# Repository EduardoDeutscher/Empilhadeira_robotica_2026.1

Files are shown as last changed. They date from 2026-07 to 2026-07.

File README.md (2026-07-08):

# Projeto Empilhadeira Robótica 2026.1

Projeto desenvolvido para a disciplina ENG4061 – Projeto de Robótica  
Prof. João Ricardo | Turma 3VA

**Integrantes:**
- Eduardo Deutscher — 2210218
- Eric Siemsen — 2210608
- Marcelo Bessa — 2220426
- Marius

---

## Descrição do Projeto

Empilhadeira robótica autônoma capaz de localizar paletes por meio de visão computacional utilizando AprilTags. O sistema realiza uma busca ativa por uma tag específica e, ao identificá-la, utiliza o algoritmo Pure Pursuit para se locomover autonomamente até o objetivo. Além do modo autônomo, o robô suporta operação manual completa, permitindo o controle em tempo real da movimentação e do garfo motorizado para elevação da carga. A transição entre os modos e o controle manual são realizados via dashboard web, acessível por qualquer dispositivo conectado à mesma rede Wi-Fi, sem necessidade de instalar nenhum aplicativo.

---

## Arquitetura do Sistema

    Câmera ⭢ Raspberry Pi ⭢ Arduino ⭢ Motores
                   ⭡
               Dashboard

O Raspberry Pi é responsável por toda a lógica de alto nível: visão computacional, máquina de estados (Busca → Pure Pursuit → Manual) e servidor web Flask com WebSockets. O Arduino Mega executa apenas os comandos recebidos via serial, acionando os motores com PWM em tempo real. A comunicação entre os dois é feita por cabo USB (Serial UART 115200 bps).

---

## Hardware Necessário

| Componente | Quantidade |
|---|---|
| Raspberry Pi 3 | 1 |
| Arduino Mega 2560 | 1 |
| Motor DC LEGO NXT 53787 (encoder) | 2 |
| Motor de passo NEMA 17 | 1 |
| Driver A4988 | 1 |
| Ponte H L298N | 1 |
| Bateria Li-Ion 18650 3.7V | 3 |
| BMS 3S 40A | 1 |
| Regulador DC-DC Buck LM2596 | 1 |
| Câmera Multilaser 480p 30fps | 1 |
| Barras de aço cilíndricas (guias) | 2 |
| Rolamentos lineares LM6UU/LM8UU | 4 |
| Filamento PLA (~1kg) | 1 |

---

---

## Dependências e Instalação

### Raspberry Pi

Crie um ambiente virtual para evitar conflitos com o sistema:

```bash
python3 -m venv ~/venv
source ~/venv/bin/activate
pip install flask flask-sock opencv-python-headless pupil-apriltags pyserial numpy
```

> Para rodar em sessões futuras, sempre ative o ambiente antes:
> ```bash
> source ~/venv/bin/activate
> ```

### Arduino IDE

Instalar via **Library Manager**:
- `AccelStepper` 

---

## Como Rodar

### 1. Subir o sketch no Arduino

- Abra `Robotica_arduino.c` na Arduino IDE
- Selecione a placa: **Ferramentas → Placa → Arduino Mega 2560**
- Selecione a porta correta em **Ferramentas → Porta**
- Clique em **Upload**

### 2. Conectar o Arduino ao Raspberry Pi via USB

O código tenta automaticamente `/dev/ttyACM0` e `/dev/ttyACM1`. Para verificar qual porta está sendo usada:

```bash
ls /dev/tty*
# antes e depois de conectar o cabo — a porta nova é a do Arduino
```

### 3. Rodar o servidor no Raspberry Pi

```bash
source ~/venv/bin/activate
python Robotica_raspberryPi.py
```

O terminal mostrará o IP e a porta ao iniciar. Aguarde as mensagens:
```bash
✅ Arduino conectado em /dev/ttyACM0!
✅ Câmera 0 conectada!
```

---

### 4. Acessar o dashboard

No celular ou notebook conectado na **mesma rede Wi-Fi** que o Pi, abra o navegador e acesse: `http://[Endereço IP]:5000` 

---

## Inicialização Automática (opcional)

Para o servidor subir automaticamente ao ligar o Pi, sem precisar de teclado ou SSH:

```bash
sudo nano /etc/rc.local
```

Adicione antes do `exit 0`:

```bash
sleep 15
source /home/pi/venv/bin/activate && cd /home/pi && python Robotica_raspberryPi.py &
```

Salve, reinicie o Pi e aguarde ~15 segundos após ligar para acessar o dashboard.

---

## Modos de Operação

### 🔍 Busca
Modo inicial autônomo. O robô para, faz um giro completo de 360° em pulsos (pausa entre cada pulso para a câmera ler sem desfoque), procurando a AprilTag alvo. Se não encontrar após a volta completa, avança um pouco para frente e repete. Se o timeout de busca for atingido (padrão: 300s), entra em modo **Parado**.

### 🎯 Pure Pursuit
Ativado ao detectar a AprilTag alvo. Opera em dois regimes:
- **Longe da tag:** Pure Pursuit clássico — calcula curvatura e decompõe em velocidades das rodas via cinemática diferencial, com rampa de desaceleração proporcional à distância.
- **Perto da tag** (< `DISTANCIA_PARAR`): para a translação e corrige apenas o ângulo girando no próprio eixo, com velocidade proporcional ao erro angular.

Ao atingir distância < 0,30 m, muda automaticamente para **Manual**.

### 🕹️ Manual
Controle total pelo dashboard. WASD para movimentação, J/K para o garfo. O slider de velocidade define a intensidade. Para retornar ao modo Busca, pressionar **Alternar Modo** no dashboard.

### ⏸️ Parado
Estado de segurança atingido por timeout de busca. Pressionar **Retomar Busca** no dashboard para reiniciar.

---

## Protocolo Serial (Pi → Arduino)

| Comando | Ação |
|---|---|
| `DE:1,VE:150,DD:1,VD:150\n`  | Move rodas com direção e velocidade PWM |
| `PARAR\n` | Para todos os motores |
| `SUBIR\n` | Garfo sobe (N passos definido no Arduino) |
| `DESCER\n` | Garfo desce (N passos definido no Arduino)  |
| `PARAR_GARFO\n` | Para o motor de passo |

Formato do comando de rodas: `DE` = direção esquerda (1/-1/0), `VE` = velocidade esquerda (0–200), `DD` = direção direita, `VD` = velocidade direita. Todos os valores são calculados pelo Pi; o Arduino apenas executa.

---

## Parâmetros Ajustáveis

Todos no topo de `Robotica_raspberryPi.py`:

| Variável | Padrão | Descrição |
|---|---|---|
| `TAG_ALVO` | `0` | ID da AprilTag a ser buscada (também ajustável no dashboard em tempo real) |
| `DISTANCIA_PARAR` | `0.30` | Distância em metros para considerar "chegou" |
| `ANGULO_ALINHADO` | `3.0`  | Graus de tolerância para considerar "alinhado" |
| `VEL_MAX` | `200`  | PWM máximo enviado aos motores (0–255) |
| `VEL_MIN` | `90` | PWM mínimo para vencer atrito estático |
| `NUM_PULSOS_360` | `12` | Número de pulsos para completar 360° na busca |
| `T_PULSO` | `0.5`  | Duração de cada pulso de giro (segundos) |
| `T_PAUSA_LEITURA` | `1.20` | Pausa entre pulsos para leitura da câmera (segundos) |
| `TIMEOUT_BUSCA_SEG`  | `300`  | Tempo máximo em busca antes de parar |
| `K_ANGULAR` | `2.5`  | Ganho da velocidade angular no Pure Pursuit |
| `L_CHASSI` | `0.15` | Distância entre rodas em metros (bitola) |

---

## Ligação dos Componentes

### Motores LEGO (tração) → Ponte H L298N → Arduino Mega

| Arduino Mega | Ponte H |
|---|---|
| Pino 11 | IN1 |
| Pino 10 | IN2 |
| Pino 13 | ENB |
| Pino 9 | IN3 |
| Pino 8 | IN4 |
| Pino 12 | ENA |
| GND | GND |

Alimentação da ponte: pack de baterias 12V → terminal VMOT.

### Motor NEMA 17 (garfo) → Driver A4988 → Arduino Mega

| Arduino Mega | A4988 |
|---|---|
| Pino 4 | STEP |
| Pino 5 | DIR |
| Pino 3 | ENABLE  |
| Pino 6 | VCC |
| GND | GND lógico |
| 5V | VDD |

Capacitor 100µF instalado em paralelo com VMOT e GND, o mais próximo possível do driver.  
Alimentação do driver: pack de baterias 12V → VMOT.

### Raspberry Pi → Arduino Mega

Conexão via cabo USB (Serial UART 115200 bps).  
Alimentação do Pi: regulador LM2596 (bateria 12V → 5V).

---

## Solução de Problemas Comuns

**Arduino não conecta:**
```bash
ls /dev/tty*  # verificar porta disponível
```
O código tenta `/dev/ttyACM0` e `/dev/ttyACM1` automaticamente. Tem reconexão automática em background se o cabo for desconectado.

**Câmera não abre:**
```bash
ls /dev/video*  # verificar índice disponível
```
O código tenta os índices 0, 1 e 2 automaticamente.

**Erro `externally-managed-environment` no pip:**
```bash
python3 -m venv ~/venv
source ~/venv/bin/activate
pip install flask flask-sock opencv-python-headless pupil-apriltags pyserial numpy
```

**Dashboard não abre pelo nome:**
Use o IP direto. Descobrir com `hostname -I` no Pi.

**Motores não reagem:**
Verificar baud rate no Serial Monitor (deve ser 115200) e confirmar que GND da fonte está conectado ao GND do Arduino.

---

## Modelagem

Link para o Onshape: `https://cad.onshape.com/documents/99c5d240e4870d25705ec42d/w/1db559e20b317aebbfff364a/e/47e8b66c013c91d15a91f58e`

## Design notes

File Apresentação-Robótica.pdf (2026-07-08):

# ENG4061 - Projeto de Robótica

Eduardo Deutscher - 2210218 Eric Siemsen - 2210608
Marcelo Bessa - 2220426
Marius -

# Objetivo

Navegação autônoma via AprilTags

Elevação de carga com garfo motorizado e controle manual

Controle manual via dashboard

# Nosso Robô

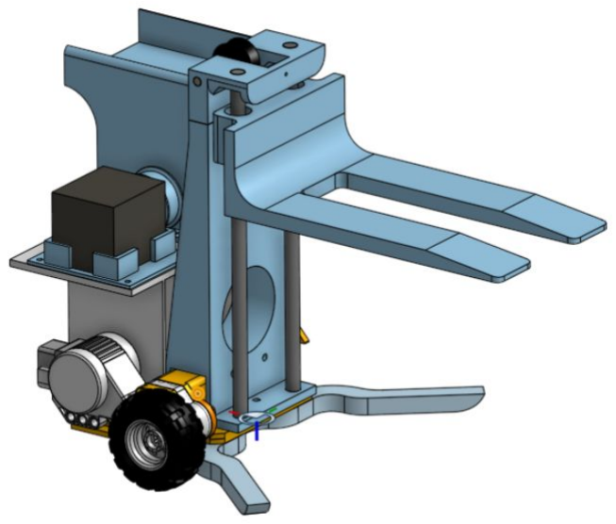
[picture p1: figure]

# Hardware

# Microcontroladores

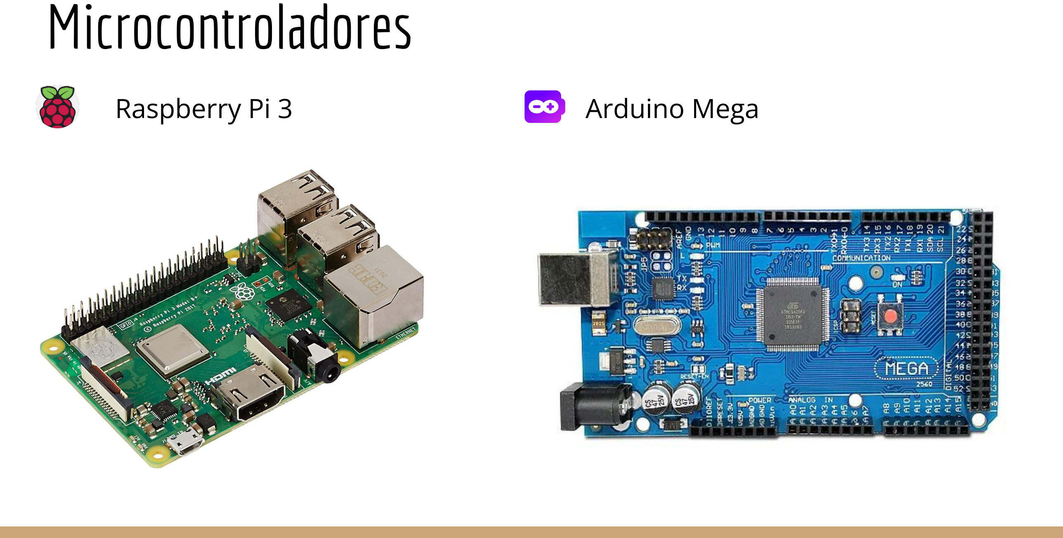
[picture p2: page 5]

Raspberry Pi 3 | Arduino Mega

# Motores

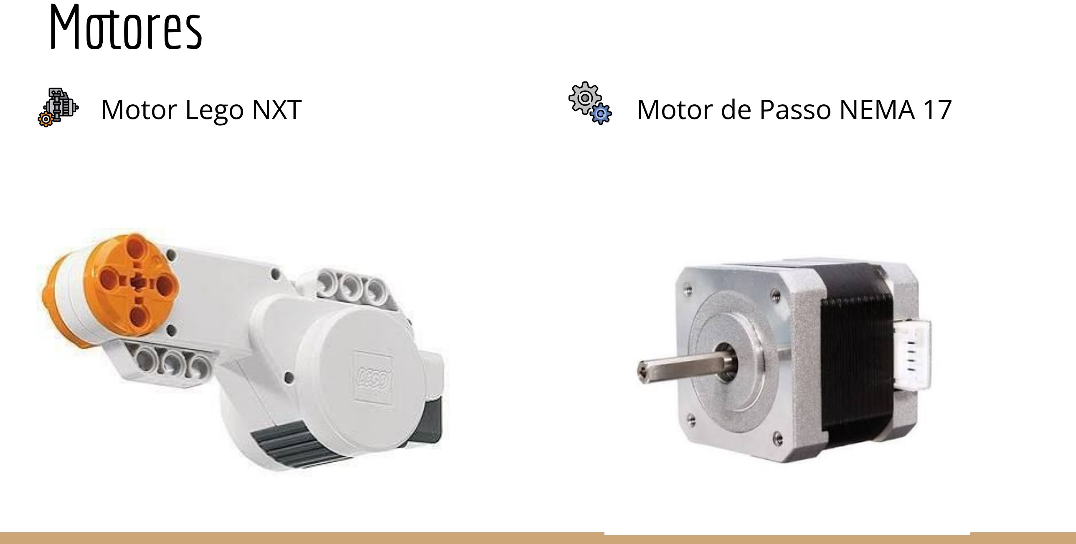
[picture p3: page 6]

Motor Lego NXT | Motor de Passo NEMA 17

# Driver e Ponte H

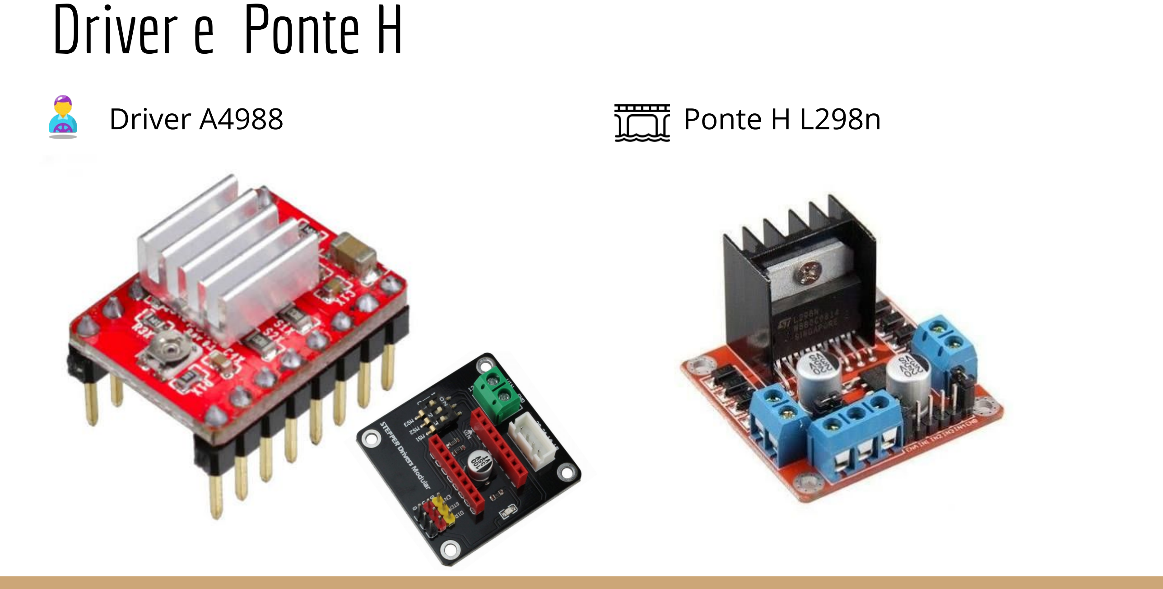
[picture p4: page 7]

Driver A4988 | Ponte H L298n

# Regulador de Tensão e Interruptores

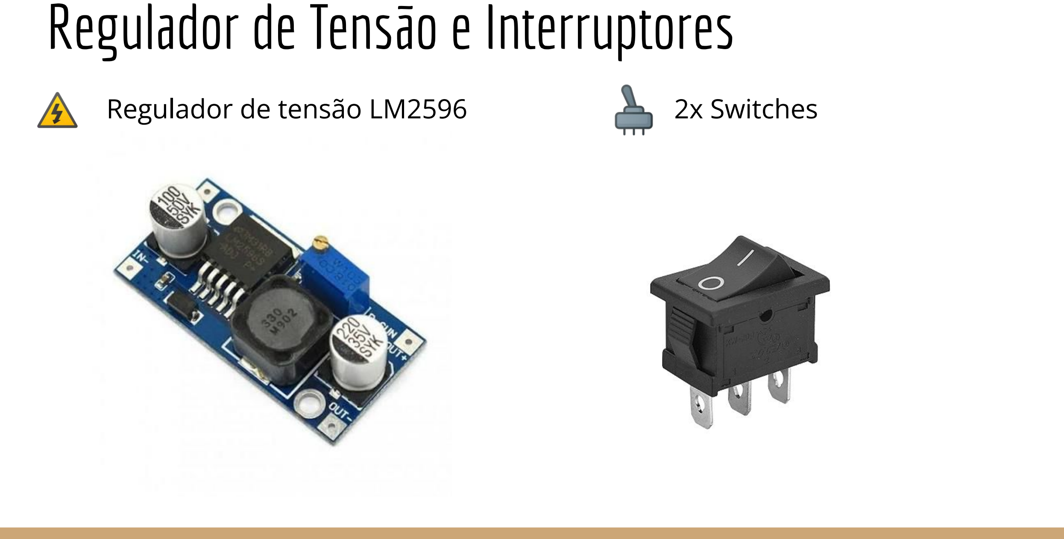
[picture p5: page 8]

Regulador de tensão LM2596 | 2x Switches

# Baterias

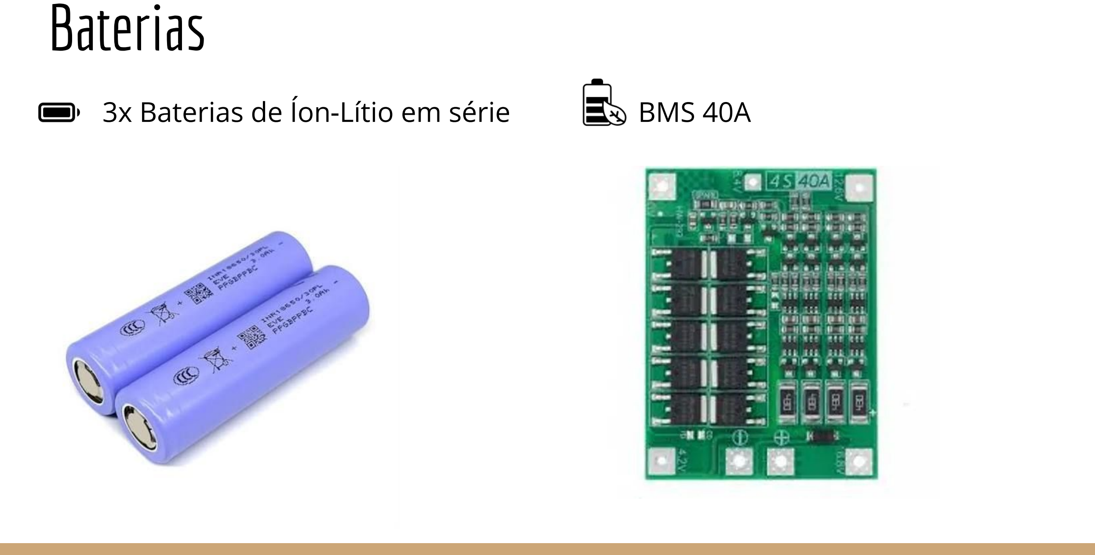
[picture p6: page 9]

3x Baterias de Íon-Lítio em série | BMS 40A

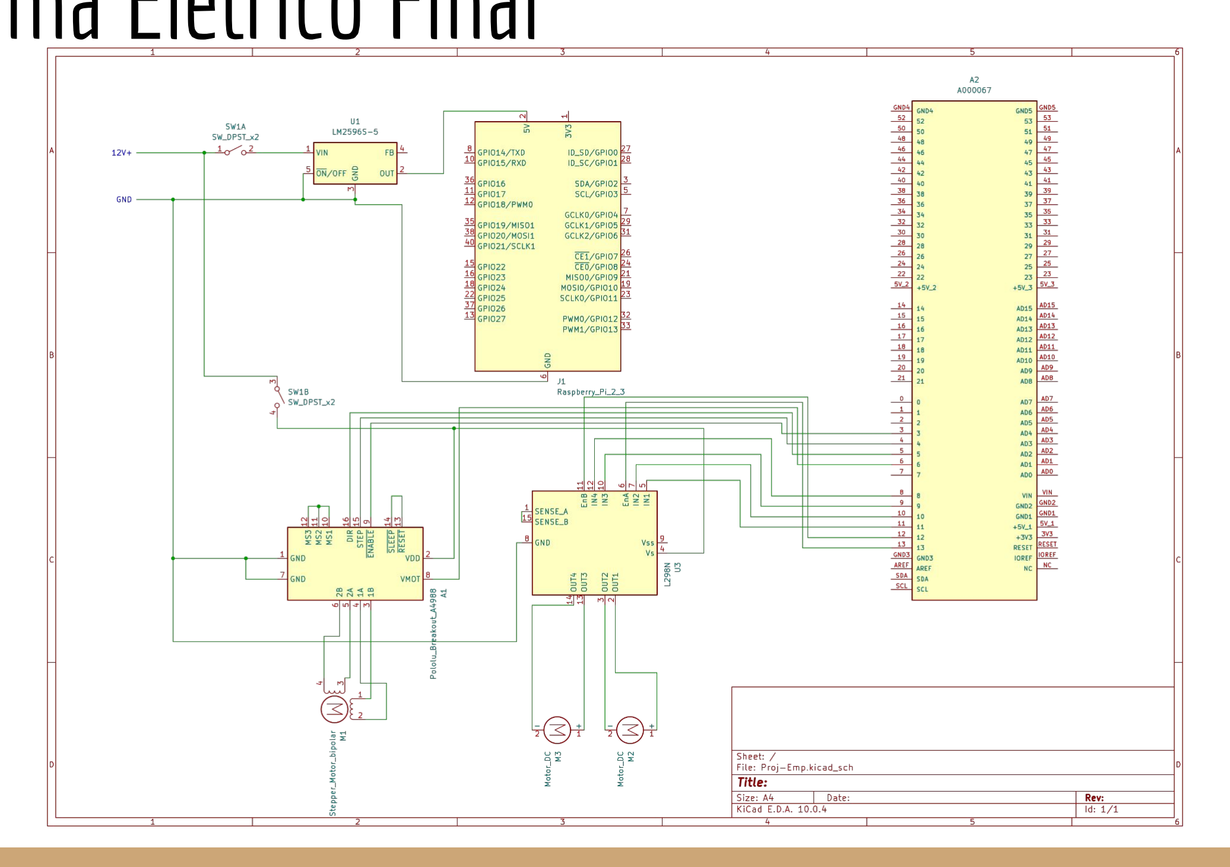
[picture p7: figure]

# Diagrama Elétrico Final

# Modelagem

# Modelagem

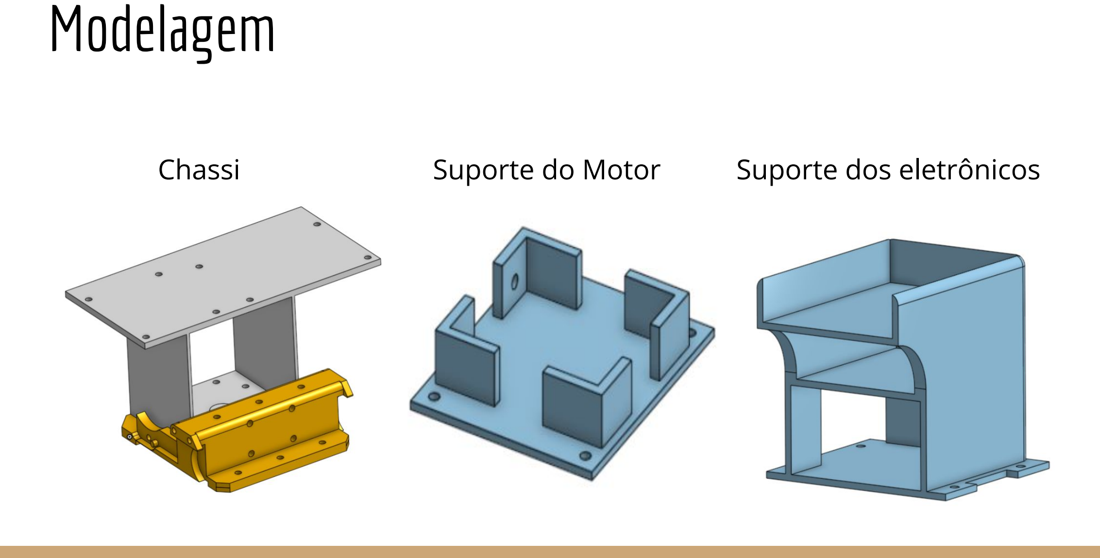
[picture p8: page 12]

Chassi | Suporte do Motor | Suporte dos eletrônicos
eletrônicoselMicros+Bateria

# Modelagem

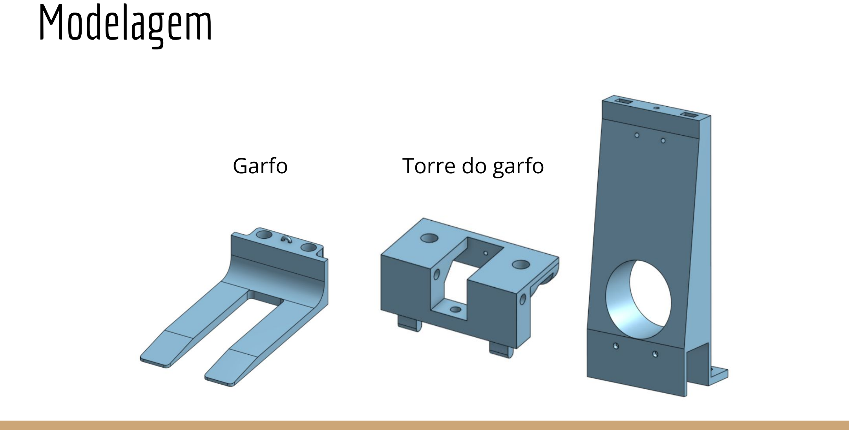
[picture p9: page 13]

Garfo | Torre do garfo

# Modelagem

Polia | Apoio Traseiro | Apoio Frontal

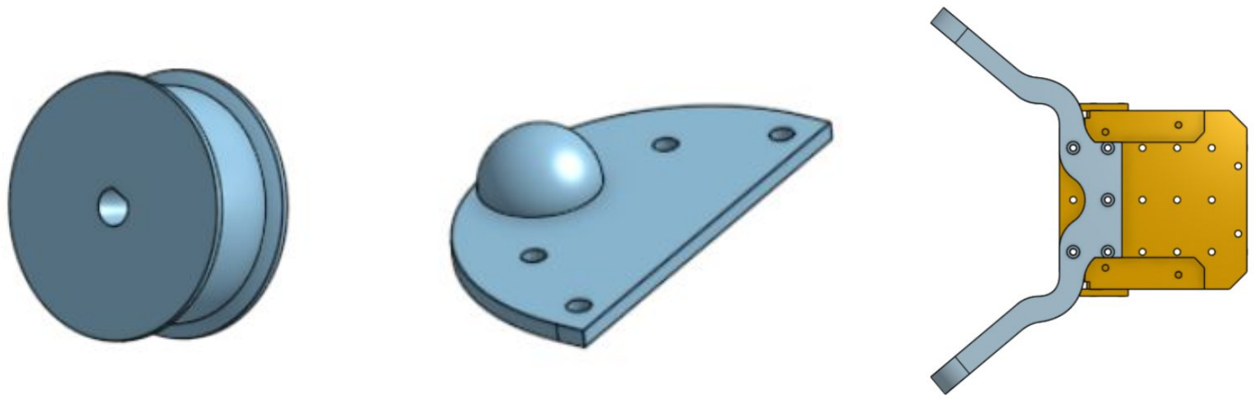
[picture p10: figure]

# Algumas mudanças…

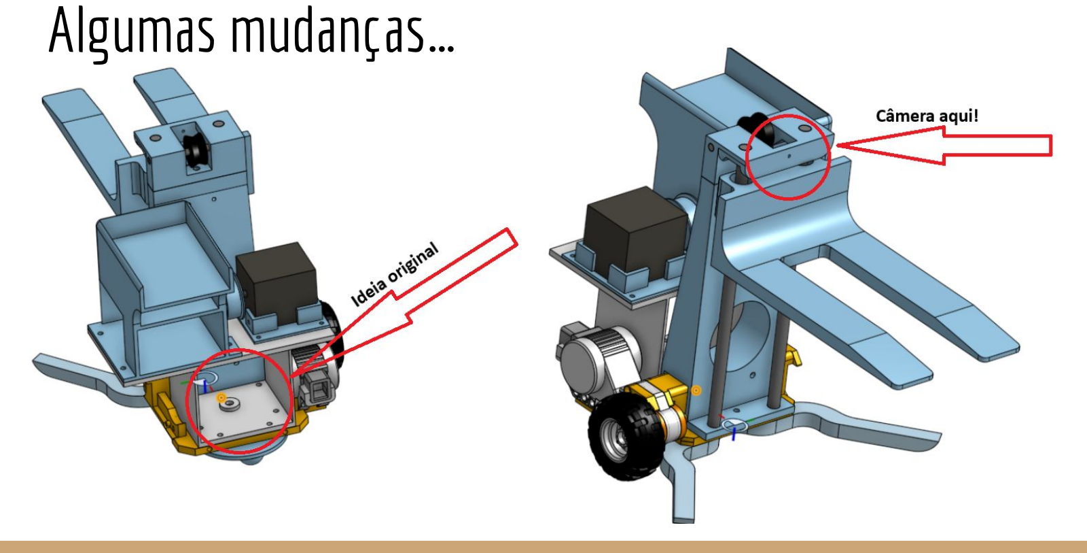
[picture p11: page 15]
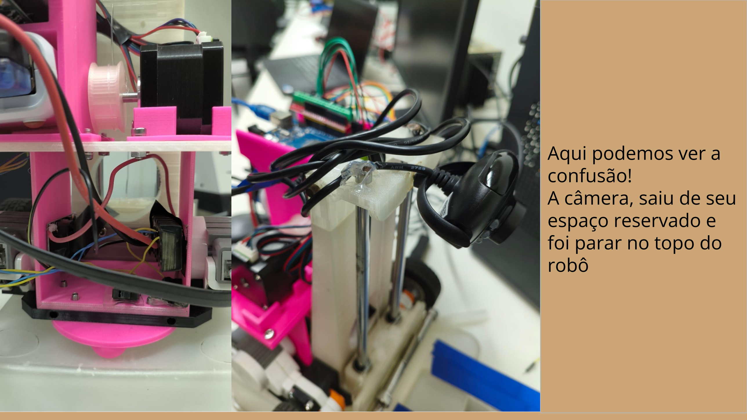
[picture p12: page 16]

Aqui podemos ver a
confusão!
A câmera, saiu de seu
espaço reservado e
foi parar no topo do
robô

# Algumas mudanças…

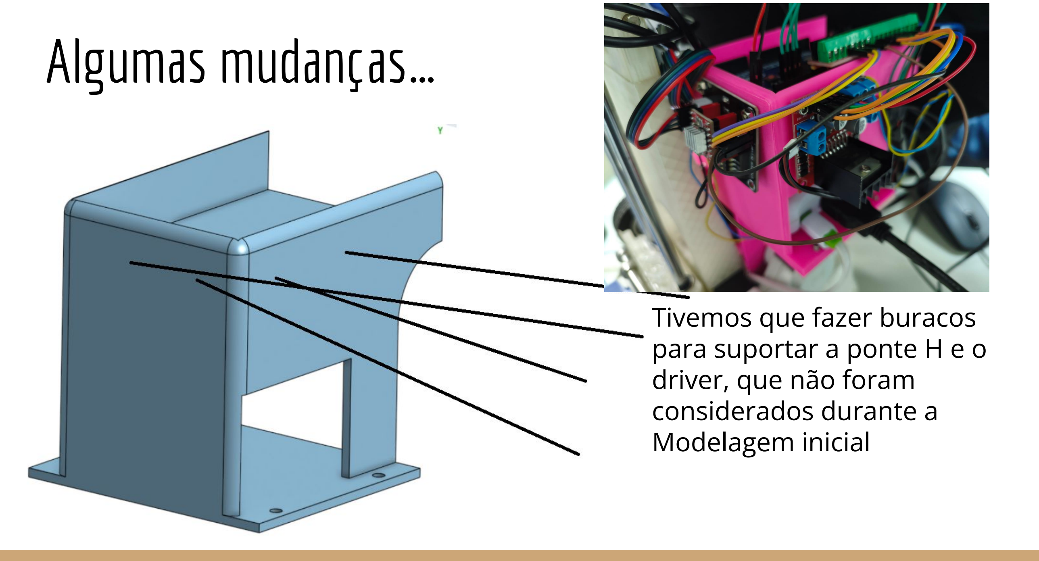
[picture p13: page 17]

Tivemos que fazer buracos
para suportar a ponte H e o driver, que não foram
considerados durante a
Modelagem inicial

# Elevação

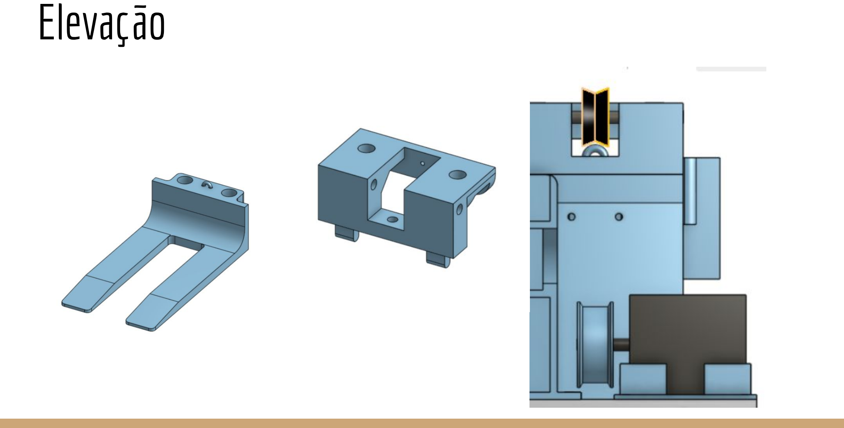
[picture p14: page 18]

# Software

# Arquitetura do Sistema

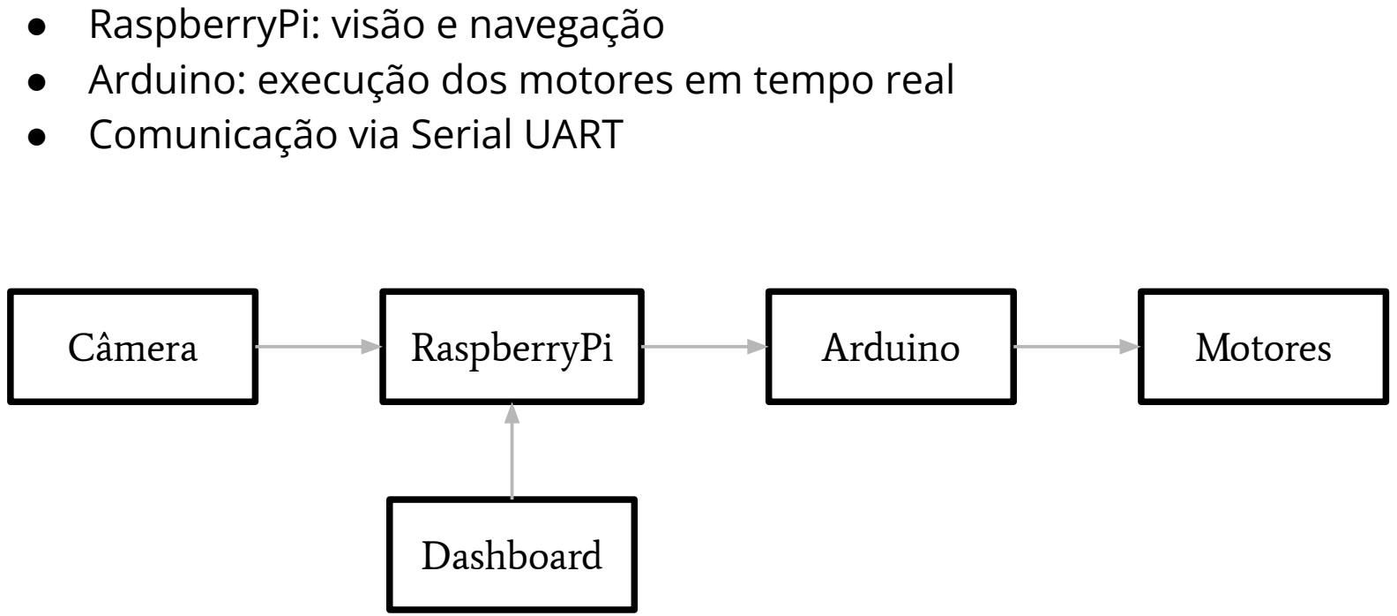
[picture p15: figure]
● RaspberryPi: visão e navegação; ● Comunicação via Serial UART; Câmera; RaspberryPi; Arduino; Motores; Dashboard

- Arduino: execução dos motores em tempo real

# Visão Computacional

- AprilTag (25h9)
- Câmera Multilaser 480p
- Calibrada no 3DF Zephyr
- Bibliotecas: OpenCV e pupil-apriltag

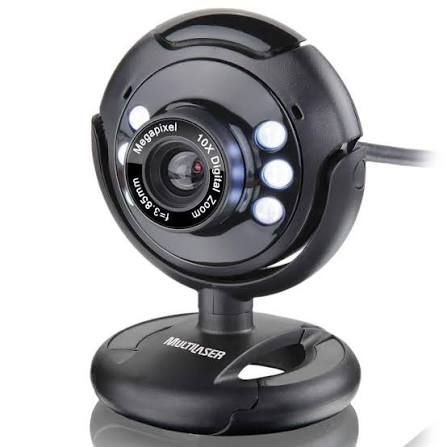
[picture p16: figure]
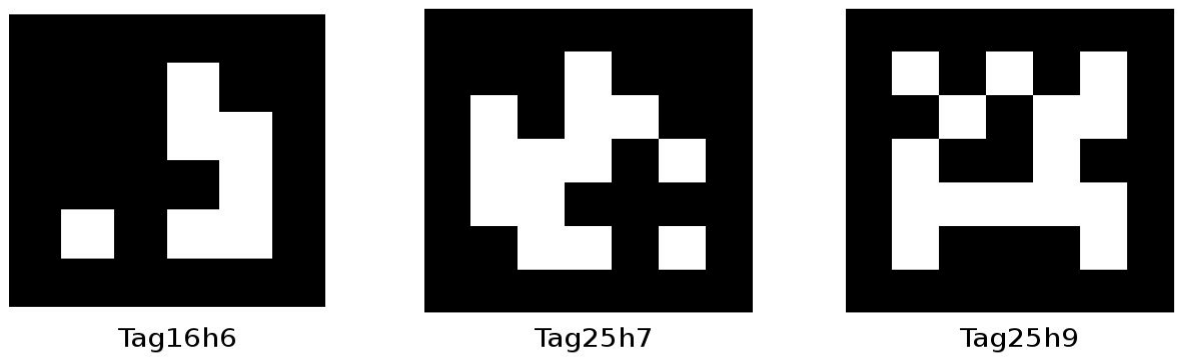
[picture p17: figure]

# Algoritmo de Navegação

- Modo Busca
- Giro 360° procurando a tag
- Algoritmo de Pure Pursuit
- Se aproxima e alinha com a tag
- Modo Manual

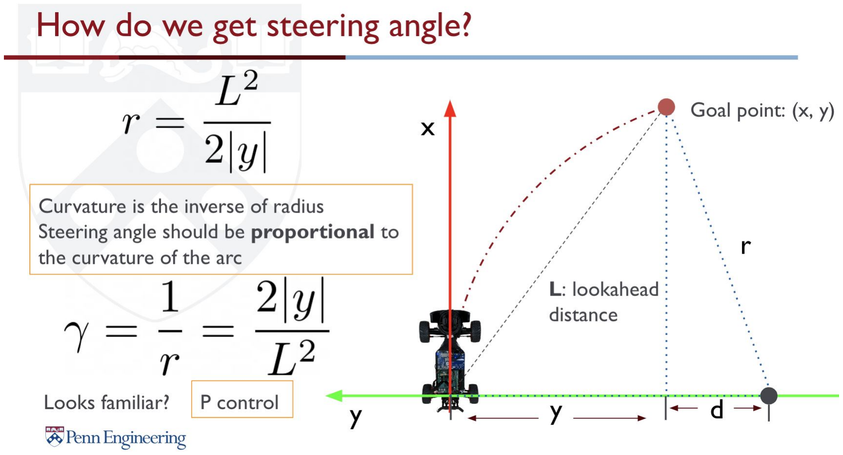
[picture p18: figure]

# Controle dos Motores

- Motores Lego NXT
- Tração diferencial via ponte H L298N
- Nema 17
- Elevação do garfo via driver A4988
- Arduino recebe comandos
- SUBIR, DESCER, DIREITA, ESQUERDA, SOBE, DESCE, PARAR

# Comunicação

# Telemetria

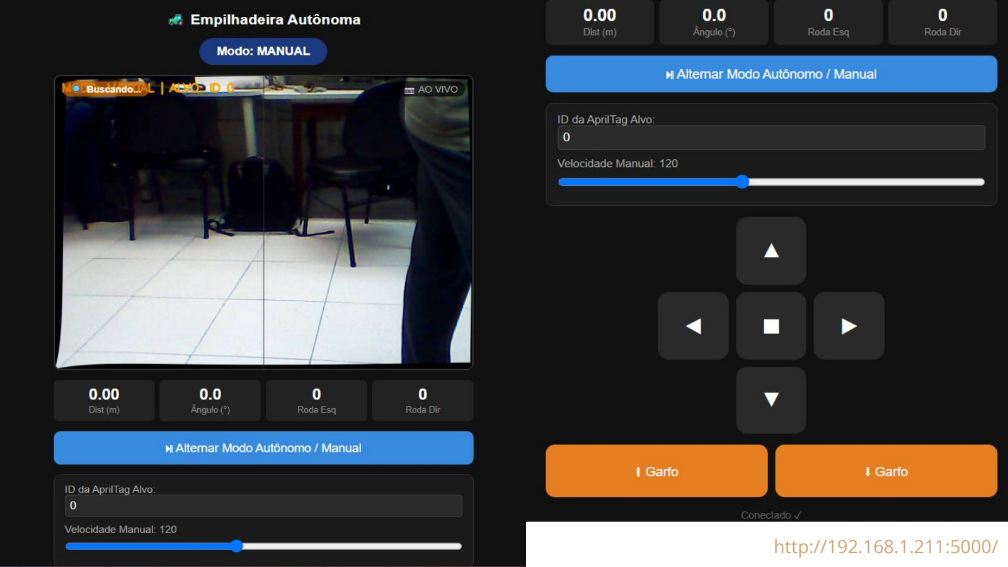
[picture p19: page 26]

http://192.168.1.211:5000/

# Cálculos

# Desafios Encontrados

# Modelagem e Construção

- Modelagem com precisão
- Integração com a parte elétrica
- Adaptação para novos componentes

# Montagem Elétrica

- Soldagem de componentes
- Driver A4988
- Fiação elétrica
- Mal contato em USBs

# Código

- Modo de busca
- Pure Pursuit
- Mudança das entradas no Raspberry Pi e Câmera
- dev/tty* e dev/video*
- Integração com a parte elétrica

# Resultado Final

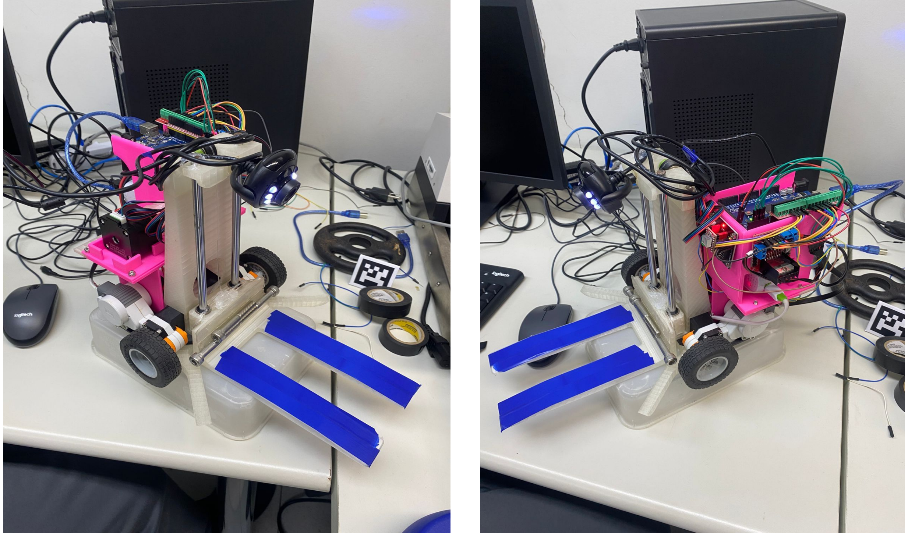
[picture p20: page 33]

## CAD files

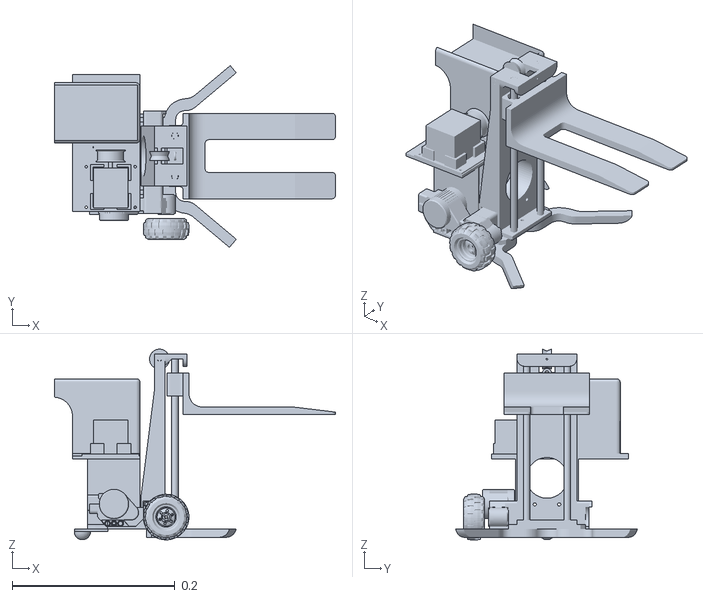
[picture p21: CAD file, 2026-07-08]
Assembly 1.stl
0.345 x 0.223 x 0.234

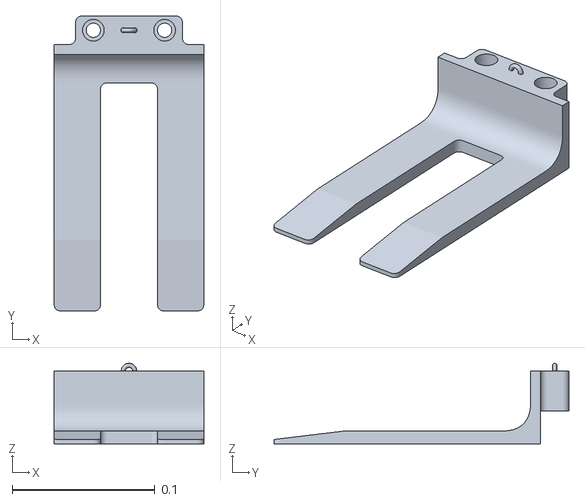
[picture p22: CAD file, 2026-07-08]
garfos.stl
0.105 x 0.207 x 0.0565

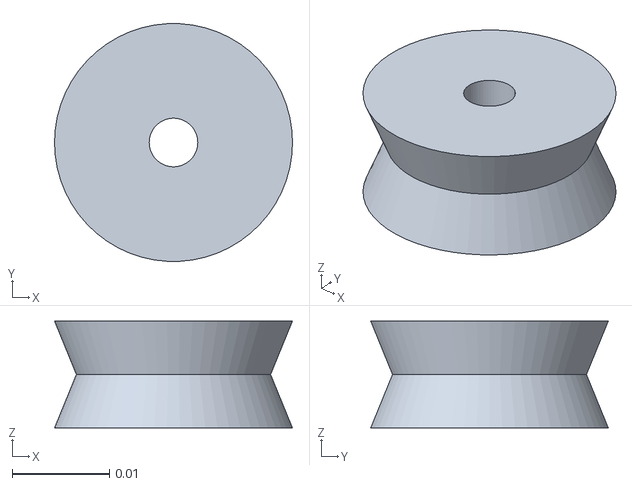
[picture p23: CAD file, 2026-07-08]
Part Studio 2.stl
0.0245 x 0.0245 x 0.011

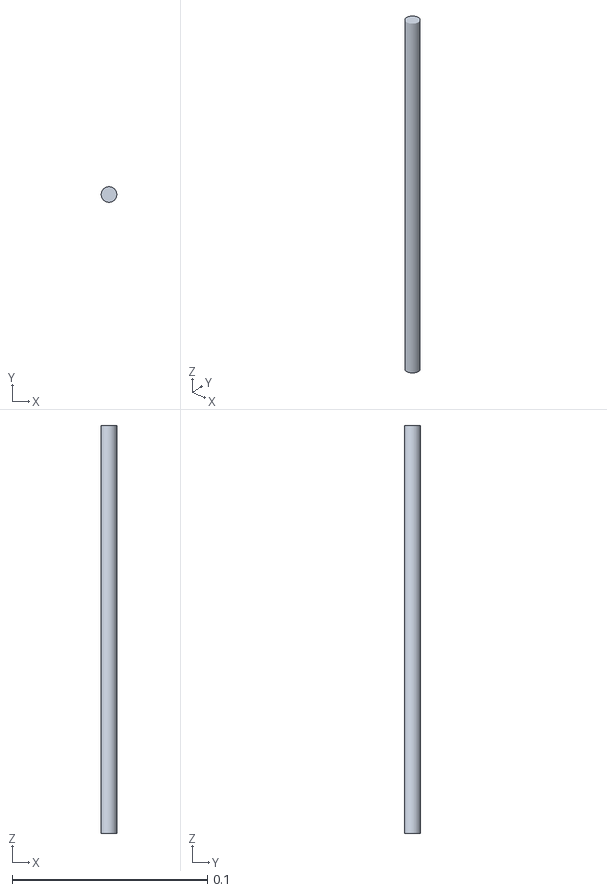
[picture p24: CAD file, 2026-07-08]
barra.stl
0.008 x 0.00799 x 0.209

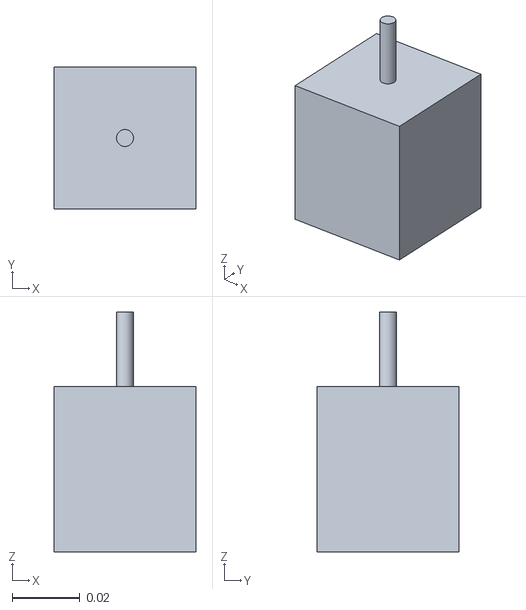
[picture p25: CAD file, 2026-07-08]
motor.stl
0.042 x 0.042 x 0.071

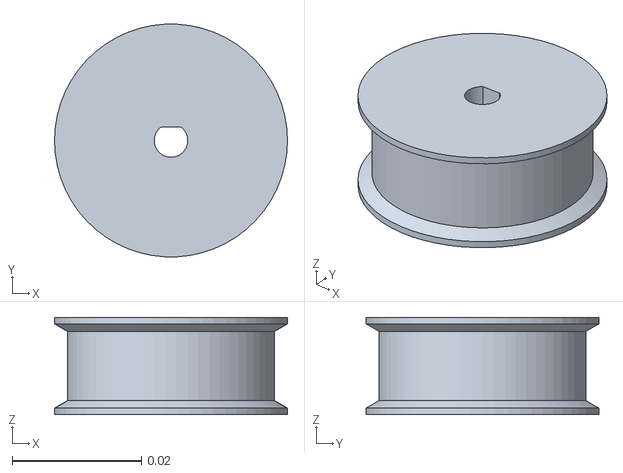
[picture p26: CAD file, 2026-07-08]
polia.stl
0.036 x 0.0359 x 0.015

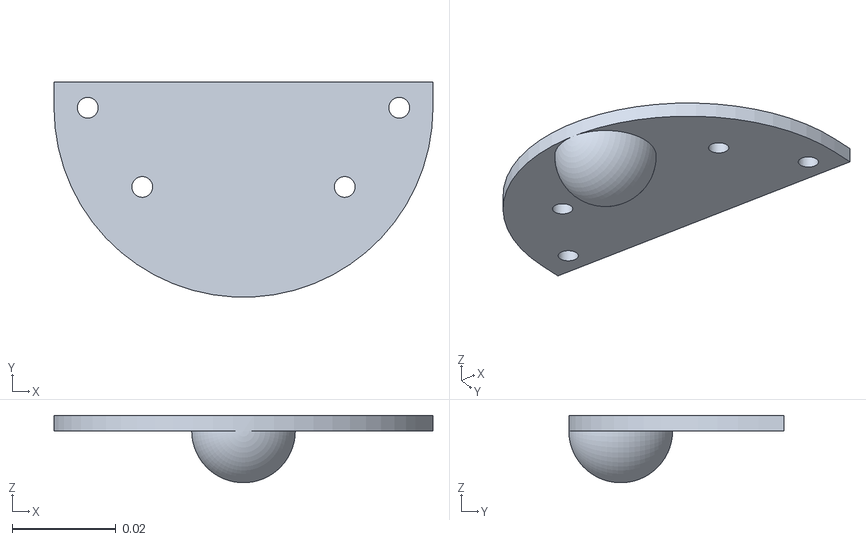
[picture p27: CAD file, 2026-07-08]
roda-de-direção.stl
0.073 x 0.0415 x 0.013

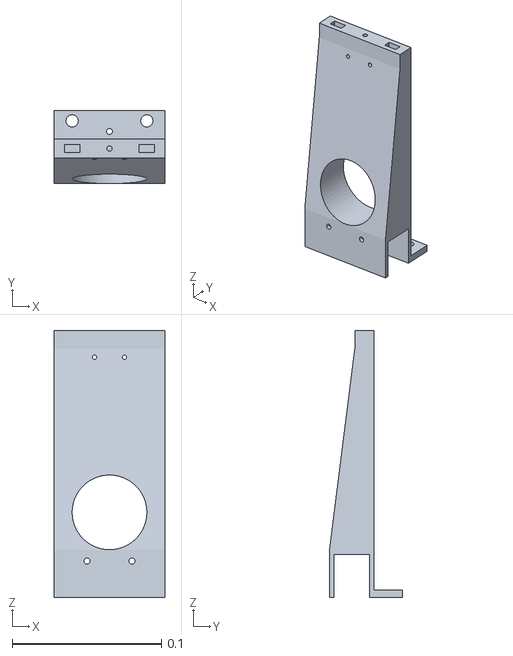
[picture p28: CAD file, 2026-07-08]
Suporte_garfos.stl
0.074 x 0.049 x 0.179

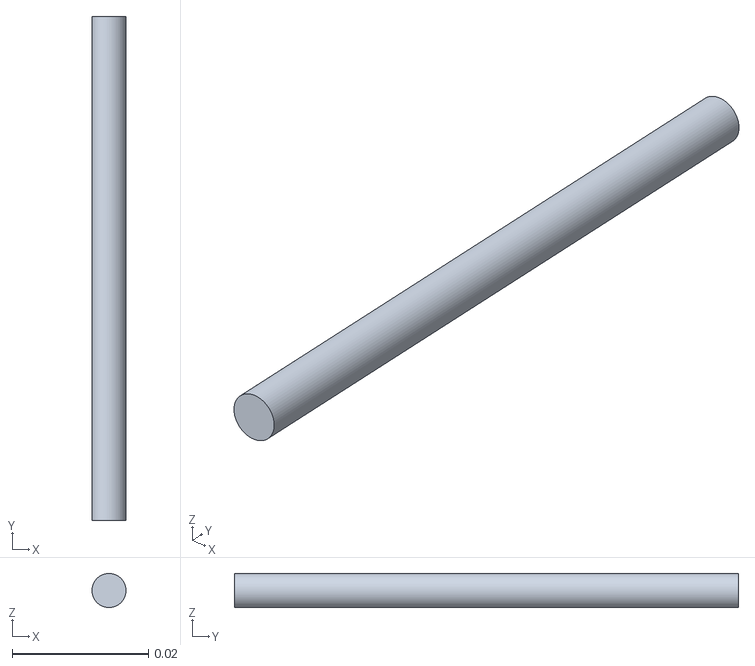
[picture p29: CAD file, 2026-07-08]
barra2.stl
0.00499 x 0.074 x 0.005

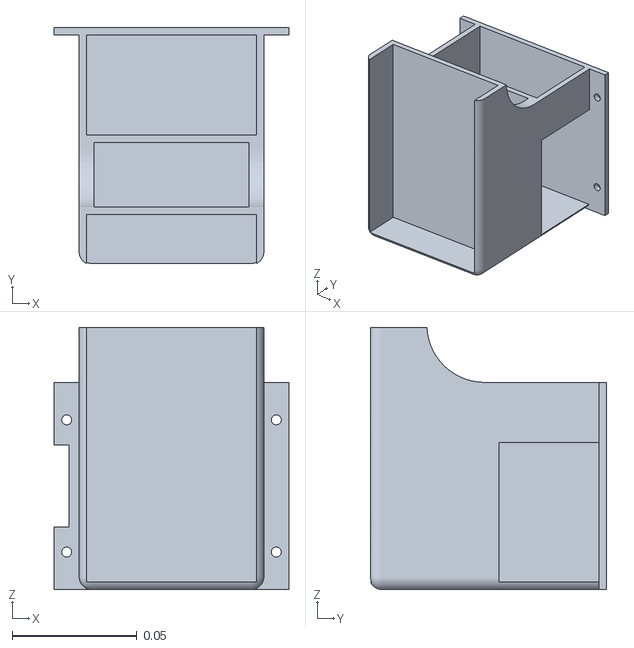
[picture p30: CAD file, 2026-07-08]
Suporte_rasp.stl
0.094 x 0.0946 x 0.105

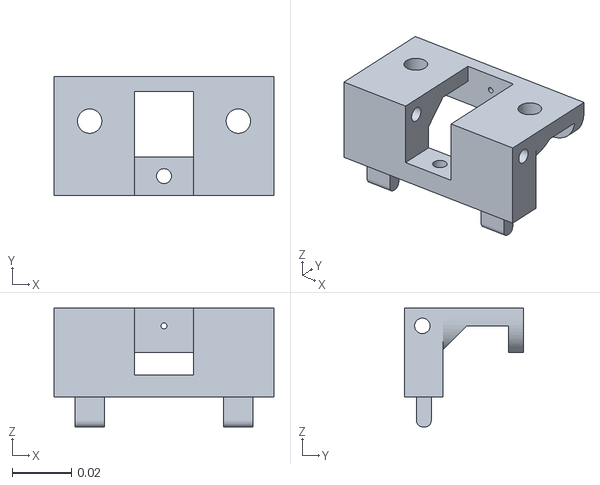
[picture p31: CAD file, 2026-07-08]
cima_suporte_garfos.stl
0.074 x 0.04 x 0.04

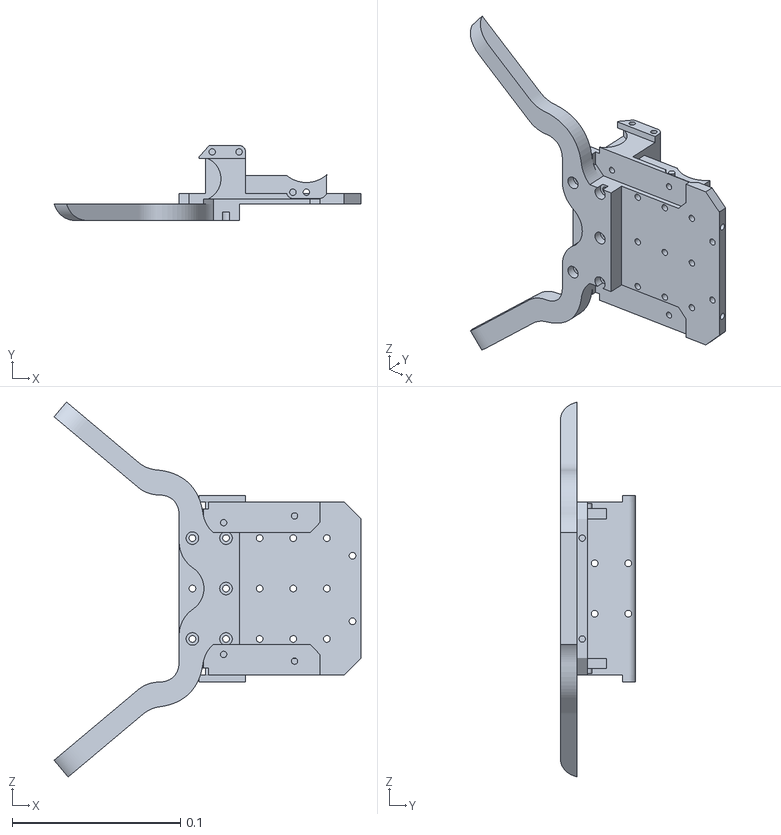
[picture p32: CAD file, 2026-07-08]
ChassiV1_central.stl
0.183 x 0.0448 x 0.223

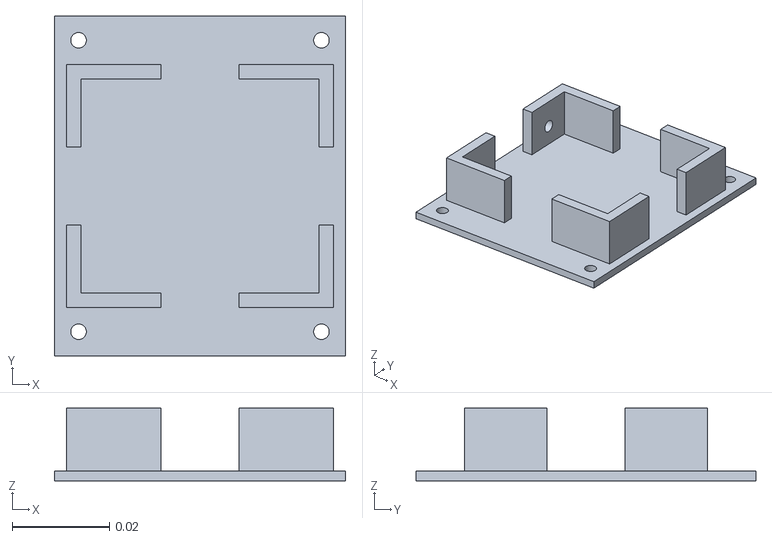
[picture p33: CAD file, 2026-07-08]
Suporte Motor de Passo.stl
0.06 x 0.07 x 0.015

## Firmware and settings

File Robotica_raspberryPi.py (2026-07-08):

from flask import Flask, render_template_string, Response
from flask_sock import Sock
import cv2
import numpy as np
from pupil_apriltags import Detector
import serial
import time
import threading
import json

# ══════════════════════════════════════════════════════════════════
# VARIÁVEIS GLOBAIS
# ══════════════════════════════════════════════════════════════════
PORTA_SERIAL          = '/dev/ttyACM0'
PORTA_SERIAL_1        = '/dev/ttyACM1'

TIMEOUT_BUSCA_SEG     = 300.0
TIMEOUT_PERDA_TAG_SEG = 1.5
DISTANCIA_PARAR       = 0.3
ANGULO_ALINHADO       = 3.0
DISTANCIA_SEGURANCA   = 0.25

K_ANGULAR             = 2.5
VEL_MAX               = 200
VEL_MIN               = 90    # velocidade mínima para vencer atrito estático

NUM_PULSOS_360   = 12
T_PULSO          = 0.5
T_PAUSA_LEITURA  = 1.20
T_FRENTE         = 1.0
VEL_GIRO_BUSCA   = 150
VEL_FRENTE_BUSCA = 180

# --- VARIÁVEIS PURE PURSUIT (STOP AND GO) ---
T_MOVIMENTO_PP   = 0.3  # Tempo que ele passa andando (segundos)
T_PAUSA_PP       = 0.6  # Tempo que ele fica parado lendo a câmera (segundos)
pp_fase          = "pausado"
pp_timer         = time.time()

L_CHASSI = 0.15
TAG_SIZE = 0.040

fx, fy = 818.035048081, 818.035048081
cx, cy = 362.333072996, 212.410243815

# ══════════════════════════════════════════════════════════════════
camera_matrix = np.array([[fx, 0, cx], [0, fy, cy], [0, 0, 1]], dtype=np.float64)
dist_coeffs   = np.array([-0.245767, 3.025417, -0.019545, 0.005721, -7.190337])
at_detector   = Detector(families='tag25h9')

BUSCA        = "busca"
PURE_PURSUIT = "pure_pursuit"
MANUAL       = "manual"
PARADO       = "parado"

estado            = MANUAL
busca_fase        = "parado_lendo"
pulsos_dados      = 0
busca_timer       = time.time()
busca_inicio      = time.time()
tag_perdida_timer = None
ultimo_cmd        = ""
tag_alvo_id       = 0

lock              = threading.Lock()

# Frame compartilhado entre thread de visão e stream MJPEG
frame_global      = None
lock_frame        = threading.Lock()

# Telemetria compartilhada para o dashboard
telemetria = {
    "dist": 0.0,
    "angulo": 0.0,
    "x": 0.0,
    "z": 0.0,
    "tag_vista": False,
    "vel_esq": 0,
    "vel_dir": 0,
}

# ══════════════════════════════════════════════════════════════════
# SERIAL E WATCHDOG
# ══════════════════════════════════════════════════════════════════
arduino = None

def conectar_arduino():
    global arduino
    if arduino is not None:
        try:
            arduino.close()
        except:
            pass
    for porta in [PORTA_SERIAL, PORTA_SERIAL_1]:
        try:
            print(f"Tentando {porta}...")
            arduino = serial.Serial(porta, 115200, timeout=1)
            time.sleep(2)
            print(f"✅ Arduino conectado em {porta}!")
            return True
        except Exception as e:
            print(f"❌ Falha em {porta}: {e}")
    arduino = None
    return False

def enviar(cmd):
    """
    Função de envio não bloqueante. Falha rápido se a conexão cair, 
    liberando a variável `arduino` para a thread do watchdog assumir.
    """
    global arduino
    if arduino:
        try:
            arduino.write((cmd + '\n').encode('utf-8'))
        except serial.SerialException as e:
            print(f"⚠️ Erro serial: {e}. Desconectando Arduino...")
            try:
                arduino.close()
            except:
                pass
            arduino = None
        except Exception as e:
            print(f"⚠️ Erro genérico serial: {e}")

def watchdog_arduino():
    """
    Thread de background que garante a reconexão do Arduino
    sem bloquear a thread de visão (OpenCV).
    """
    global arduino
    while True:
        if arduino is None:
            print("🔄 Tentando reconectar ao Arduino em background...")
            conectar_arduino()
        time.sleep(2)

conectar_arduino()

# ══════════════════════════════════════════════════════════════════
# MOVIMENTO
# ══════════════════════════════════════════════════════════════════
def enviar_rodas(vel_esq, vel_dir):
    # Garante velocidade mínima para vencer o atrito (zona morta do motor)
    def aplicar_zona_morta(v):
        if v == 0:
            return 0
        return int(np.sign(v) * max(VEL_MIN, abs(v)))

    vel_esq = aplicar_zona_morta(int(np.clip(vel_esq, -VEL_MAX, VEL_MAX)))
    vel_dir = aplicar_zona_morta(int(np.clip(vel_dir, -VEL_MAX, VEL_MAX)))

    dir_esq = 1 if vel_esq > 0 else (-1 if vel_esq < 0 else 0)
    dir_dir = 1 if vel_dir > 0 else (-1 if vel_dir < 0 else 0)

    with lock:
        telemetria["vel_esq"] = vel_esq
        telemetria["vel_dir"] = vel_dir

    enviar(f"DE:{dir_esq},VE:{abs(vel_esq)},DD:{dir_dir},VD:{abs(vel_dir)}")

# ══════════════════════════════════════════════════════════════════
# PURE PURSUIT — MELHORADO
# ══════════════════════════════════════════════════════════════════
def pure_pursuit_para_rodas(x, z):
    distancia = np.sqrt(x**2 + z**2)
    angulo    = np.degrees(np.arctan2(x, z))

    # ── Fase 1: longe — Pure Pursuit clássico ──────────────────
    if distancia > DISTANCIA_PARAR:
        L = distancia
        curvatura = (2.0 * x) / (L**2)
        
        # 1. Ajuste da Rampa de Desaceleração:
        fator_dist = (L - DISTANCIA_PARAR) / 0.7
        v_norm     = np.clip(fator_dist, 0.45, 1.0) 

        w_norm       = v_norm * curvatura * K_ANGULAR
        
        vel_esq_norm = v_norm - w_norm * L_CHASSI / 2
        vel_dir_norm = v_norm + w_norm * L_CHASSI / 2

        # 2. Normalização:
        max_norm = max(abs(vel_esq_norm), abs(vel_dir_norm), 1.0)
        vel_esq_norm /= max_norm
        vel_dir_norm /= max_norm

        return int(vel_esq_norm * VEL_MAX), int(vel_dir_norm * VEL_MAX)

    # ── Fase 2: perto — só corrige ângulo girando no eixo ─────
    # if abs(angulo) < ANGULO_ALINHADO:
    #    return 0, 0   # alinhado — sinaliza chegada

    # 3. Ajuste do Giro no Próprio Eixo:
    vel_giro = int(np.clip(abs(angulo) * 3.0, VEL_MIN, VEL_MAX))

    if angulo > 0:
        return vel_giro, -vel_giro
    else:
        return -vel_giro, vel_giro

# ══════════════════════════════════════════════════════════════════
# MODO BUSCA
# ══════════════════════════════════════════════════════════════════
def atualizar_busca():
    global busca_fase, busca_timer, busca_inicio, estado, pulsos_dados

    if time.time() - busca_inicio > TIMEOUT_BUSCA_SEG:
        print("Timeout de busca excedido.")
        enviar("PARAR")
        with lock:
            estado = PARADO
        return

    decorrido = time.time() - busca_timer

    if busca_fase == "parado_lendo":
        enviar("PARAR")
        if decorrido > T_PAUSA_LEITURA:
            if pulsos_dados >= NUM_PULSOS_360:
                busca_fase  = "frente"
                busca_timer = time.time()
            else:
                busca_fase  = "girando"
                busca_timer = time.time()

    elif busca_fase == "girando":
        if decorrido > T_PULSO:
            enviar("PARAR") 
            pulsos_dados += 1
            busca_fase   = "parado_lendo"
            busca_timer  = time.time()
        else:
            enviar_rodas(-VEL_GIRO_BUSCA, VEL_GIRO_BUSCA)
    
    elif busca_fase == "frente":
        if decorrido > T_FRENTE:
            enviar("PARAR") # Evita que o robô dê um tranco para frente no frame de transição
            pulsos_dados = 0
            busca_fase   = "parado_lendo"
            busca_timer  = time.time()
        else:
            enviar_rodas(VEL_FRENTE_BUSCA, VEL_FRENTE_BUSCA)

def resetar_busca():
    global busca_fase, busca_timer, busca_inicio, pulsos_dados
    busca_fase   = "parado_lendo"
    busca_timer  = time.time()
    busca_inicio = time.time()
    pulsos_dados = 0

# ══════════════════════════════════════════════════════════════════
# THREAD DE VISÃO E RECONEXÃO DE CÂMERA
# ══════════════════════════════════════════════════════════════════
def conectar_camera():
    for idx in [0, 1, 2]:
        print(f"Tentando câmera {idx}...")
        temp = cv2.VideoCapture(idx)
        if temp.isOpened():
            ret, _ = temp.read()
            if ret:
                temp.set(cv2.CAP_PROP_FRAME_WIDTH, 640)
                temp.set(cv2.CAP_PROP_FRAME_HEIGHT, 480)
                print(f"✅ Câmera {idx} conectada!")
                return temp
        temp.release()
        time.sleep(0.5)
    return None

def thread_visao():
    global estado, tag_perdida_timer, ultimo_cmd, tag_alvo_id, frame_global
    global pp_fase, pp_timer

    cap = conectar_camera()
    if cap is None:
        print("❌ Nenhuma câmera detectada na inicialização.")

    w_frame = 640
    h_frame = 480
    new_cam, _ = cv2.getOptimalNewCameraMatrix(
        camera_matrix, dist_coeffs, (w_frame, h_frame), 1, (w_frame, h_frame)
    )

    falhas_camera = 0

    while True:
        if cap is None or not cap.isOpened():
            print("❌ Câmera offline. Tentando reconectar...")
            cap = conectar_camera()
            if cap is None:
                time.sleep(1)
                continue
            else:
                falhas_camera = 0

        ret, frame = cap.read()
        
        if not ret:
            falhas_camera += 1
            if falhas_camera > 15:
                print("⚠️ Câmera travou. Reiniciando conexão de vídeo...")
                cap.release()
                cap = None
            time.sleep(0.01)
            continue
            
        falhas_camera = 0

        und  = cv2.undistort(frame, camera_matrix, dist_coeffs, None, new_cam)
        gray = cv2.cvtColor(und, cv2.COLOR_BGR2GRAY)

        results = at_detector.detect(
            gray,
            estimate_tag_pose=True,
            camera_params=[new_cam[0,0], new_cam[1,1], new_cam[0,2], new_cam[1,2]],
            tag_size=TAG_SIZE
        )

        tag_detectada = False
        x, z = 0.0, 0.0

        with lock:
            alvo_atual = tag_alvo_id
            modo       = estado

        for r in results:
            cor = (0, 255, 0) if r.tag_id == alvo_atual else (128, 128, 128)
            cv2.polylines(und, [r.corners.astype(np.int32)], True, cor, 2)
            cv2.putText(und, f"ID:{r.tag_id}", (int(r.corners[0][0]), int(r.corners[0][1]) - 8),
                        cv2.FONT_HERSHEY_SIMPLEX, 0.5, cor, 1)

            if r.tag_id == alvo_atual:
                tag_detectada = True
                x = r.pose_t[0][0]
                z = r.pose_t[2][0]

        distancia = float(np.sqrt(x**2 + z**2)) if tag_detectada else 0.0
        angulo    = float(np.degrees(np.arctan2(x, z))) if tag_detectada else 0.0

        with lock:
            telemetria["dist"]      = round(distancia, 3)
            telemetria["angulo"]    = round(angulo, 1)
            telemetria["x"]         = round(float(x), 3)
            telemetria["z"]         = round(float(z), 3)
            telemetria["tag_vista"] = tag_detectada

        cor_modo = {
            BUSCA: (255,165,0), PURE_PURSUIT: (0,255,0),
            MANUAL: (0,165,255), PARADO: (0,0,255)
        }.get(modo, (255,255,255))

        cv2.putText(und, f"MODO: {modo.upper()} | ALVO: ID {alvo_atual}",
                    (10, 25), cv2.FONT_HERSHEY_SIMPLEX, 0.6, cor_modo, 2)

        if tag_detectada:
            cv2.putText(und, f"Dist:{distancia:.2f}m  Ang:{angulo:.1f}deg  X:{x:.2f}  Z:{z:.2f}",
                        (10, 50), cv2.FONT_HERSHEY_SIMPLEX, 0.5, (0,255,0), 1)

        h, w = und.shape[:2]
        cv2.line(und, (w//2, 0), (w//2, h), (50, 50, 50), 1)

        _, jpeg = cv2.imencode('.jpg', und, [cv2.IMWRITE_JPEG_QUALITY, 70])
        with lock_frame:
            frame_global = jpeg.tobytes()

        # Máquina de estados
        if modo == BUSCA:
            if tag_detectada:
                print(f"Tag {alvo_atual} encontrada! Pure Pursuit.")
                resetar_busca()
                with lock:
                    estado = PURE_PURSUIT
                    tag_perdida_timer = None
                    pp_fase = "pausado"
                    pp_timer = time.time()
            else:
                atualizar_busca()

        elif modo == PURE_PURSUIT:
            if not tag_detectada:
                if tag_perdida_timer is None:
                    tag_perdida_timer = time.time()
                elif time.time() - tag_perdida_timer > TIMEOUT_PERDA_TAG_SEG:
                    print("Tag perdida. Voltando para busca.")
                    enviar("PARAR")
                    resetar_busca()
                    with lock:
                        estado = BUSCA
                        tag_perdida_timer = None
            else:
                tag_perdida_timer = None
                distancia = np.sqrt(x**2 + z**2)
                angulo    = np.degrees(np.arctan2(x, z))

                if distancia < DISTANCIA_PARAR and abs(angulo) < ANGULO_ALINHADO:
                    print(f"Alinhado! Dist:{distancia:.2f}m Ang:{angulo:.1f}°. MANUAL.")
                    enviar("PARAR")
                    with lock:
                        estado = MANUAL
                else:
                    decorrido_pp = time.time() - pp_timer

                    if pp_fase == "movendo":
                        vel_esq, vel_dir = pure_pursuit_para_rodas(x, z)
                        cmd = f"{vel_esq},{vel_dir}"
                        if cmd != ultimo_cmd:
                            enviar_rodas(vel_esq, vel_dir)
                            ultimo_cmd = cmd
                        
                        if decorrido_pp > T_MOVIMENTO_PP:
                            pp_fase = "pausado"
                            pp_timer = time.time()
                            enviar("PARAR")
                            ultimo_cmd = "PARAR"
                            
                    elif pp_fase == "pausado":
                        if decorrido_pp > T_PAUSA_PP:
                            pp_fase = "movendo"
                            pp_timer = time.time()

        elif modo in (MANUAL, PARADO):
            pass

# ══════════════════════════════════════════════════════════════════
# FLASK
# ══════════════════════════════════════════════════════════════════
app  = Flask(__name__)
sock = Sock(app)

@app.route('/video')
def video():
    def gerar():
        while True:
            with lock_frame:
                f = frame_global
            if f is None:
                time.sleep(0.05)
                continue
            yield (b'--frame\r\n'
                   b'Content-Type: image/jpeg\r\n\r\n' + f + b'\r\n')
            time.sleep(0.05)
    return Response(gerar(), mimetype='multipart/x-mixed-replace; boundary=frame')

HTML = """
<!DOCTYPE html>
<html>
<head>
  <meta charset="UTF-8">
  <meta name="viewport" content="width=device-width, initial-scale=1.0">
  <title>Dashboard Empilhadeira</title>
  <style>
    * { box-sizing:border-box; margin:0; padding:0; }
    body { background:#111; color:#fff; font-family:sans-serif;
           display:flex; flex-direction:column; align-items:center;
           padding:16px; gap:12px; }
    h2 { font-size:17px; }
    #modo { font-size:14px; padding:8px 20px; border-radius:99px;
            background:#333; font-weight:bold; }

    /* Feed de câmera */
    #camera-wrap { width:100%; max-width:480px; aspect-ratio:4/3;
                   background:#000; border-radius:8px; overflow:hidden;
                   border:2px solid #333; position:relative; }
    #camera-wrap img { width:100%; height:100%; object-fit:contain; }
    #cam-badge { position:absolute; top:6px; right:8px; font-size:11px;
                 background:rgba(0,0,0,0.6); padding:2px 8px;
                 border-radius:99px; color:#aaa; }
    #tag-badge { position:absolute; top:6px; left:8px; font-size:11px;
                 padding:2px 10px; border-radius:99px; font-weight:bold; }

    /* Telemetria */
    .telem { display:grid; grid-template-columns:repeat(4,1fr);
             gap:6px; width:100%; max-width:480px; }
    .tbox { background:#222; border-radius:6px; padding:8px 4px;
            text-align:center; }
    .tbox .val { font-size:18px; font-weight:bold; }
    .tbox .lbl { font-size:10px; color:#888; margin-top:2px; }

    .btn-modo { padding:11px 0; font-size:14px; border:none; border-radius:8px;
                background:#378ADD; color:#fff; cursor:pointer;
                width:100%; max-width:480px; }
    .btn-retomar { background:#1D9E75; }

    .config-panel { background:#1a1a1a; padding:10px 12px; border-radius:8px;
                    width:100%; max-width:480px; display:flex;
                    flex-direction:column; gap:8px; border:1px solid #333; }
    .config-panel label { font-size:12px; color:#aaa; }
    input[type="number"], input[type="range"] {
      width:100%; padding:5px; background:#2a2a2a; color:#fff;
      border:1px solid #444; border-radius:4px; }

    .grid { display:grid; grid-template-columns:repeat(3,75px);
            grid-template-rows:repeat(3,75px); gap:8px; }
    .btn { width:75px; height:75px; font-size:22px; border:none;
           border-radius:12px; background:#2a2a2a; color:#fff;
           cursor:pointer; touch-action:manipulation; user-select:none; }
    .btn:active { background:#555; }
    .empty { background:transparent !important; pointer-events:none; }

    .garfo { display:flex; gap:8px; width:100%; max-width:480px; }
    .btn-garfo { flex:1; height:58px; font-size:14px; border:none;
                 border-radius:10px; background:#e67e22; color:#fff;
                 cursor:pointer; touch-action:manipulation; user-select:none; }
    .btn-garfo:active { background:#d35400; }
    #status { font-size:11px; color:#666; }
  </style>
</head>
<body>

  <h2>🚜 Empilhadeira Autônoma</h2>
  <div id="modo">Modo: —</div>

  <div id="camera-wrap">
    <img src="/video" alt="Feed da câmera">
    <div id="cam-badge">📷 AO VIVO</div>
    <div id="tag-badge">—</div>
  </div>

  <div class="telem">
    <div class="tbox"><div class="val" id="t_dist">—</div><div class="lbl">Dist (m)</div></div>
    <div class="tbox"><div class="val" id="t_ang">—</div><div class="lbl">Ângulo (°)</div></div>
    <div class="tbox"><div class="val" id="t_ve">—</div><div class="lbl">Roda Esq</div></div>
    <div class="tbox"><div class="val" id="t_vd">—</div><div class="lbl">Roda Dir</div></div>
  </div>

  <button class="btn-modo" onclick="cmd('ALTERNAR')">⏯ Alternar Modo Autônomo / Manual</button>
  <button class="btn-modo btn-retomar" id="btn-retomar"
          onclick="cmd('RETOMAR')" style="display:none">▶ Retomar Busca</button>

  <div class="config-panel">
    <label>ID da AprilTag Alvo:
      <input type="number" id="tag_id_input" value="0" min="0" max="100"
             onchange="atualizarTagId()">
    </label>
    <label>Velocidade Manual: <span id="vel_label">140</span>
      <input type="range" id="slider" min="60" max="220" value="140"
             oninput="document.getElementById('vel_label').textContent=this.value">
    </label>
  </div>

  <div class="grid">
    <div class="btn empty"></div>
    <button class="btn" ontouchstart="mv(1,1)"   ontouchend="stop()"
                        onmousedown="mv(1,1)"    onmouseup="stop()">▲</button>
    <div class="btn empty"></div>

    <button class="btn" ontouchstart="mv(-1,1)"  ontouchend="stop()"
                        onmousedown="mv(-1,1)"   onmouseup="stop()">◀</button>
    <button class="btn" onclick="stop()">⏹</button>
    <button class="btn" ontouchstart="mv(1,-1)"  ontouchend="stop()"
                        onmousedown="mv(1,-1)"   onmouseup="stop()">▶</button>

    <div class="btn empty"></div>
    <button class="btn" ontouchstart="mv(-1,-1)" ontouchend="stop()"
                        onmousedown="mv(-1,-1)"  onmouseup="stop()">▼</button>
    <div class="btn empty"></div>
  </div>

  <div class="garfo">
    <button class="btn-garfo" ontouchstart="cmd('SUBIR')"  ontouchend="cmd('PARAR_GARFO')"
                              onmousedown="cmd('SUBIR')"  onmouseup="cmd('PARAR_GARFO')">
      ⬆ Garfo</button>
    <button class="btn-garfo" ontouchstart="cmd('DESCER')" ontouchend="cmd('PARAR_GARFO')"
                              onmousedown="cmd('DESCER')" onmouseup="cmd('PARAR_GARFO')">
      ⬇ Garfo</button>
  </div>

  <div id="status">Conectando...</div>

  <script>
    const ws = new WebSocket('ws://' + location.host + '/ws');

    ws.onopen  = () => document.getElementById('status').textContent = 'Conectado ✓';
    ws.onclose = () => document.getElementById('status').textContent = 'Desconectado ✗';

    ws.onmessage = (e) => {
      const data = JSON.parse(e.data);

      if (data.modo) {
        const cores = { busca:'#7A4800', pure_pursuit:'#1D6B3A',
                        manual:'#1D3A80', parado:'#6B1D1D' };
        const el = document.getElementById('modo');
        el.textContent      = 'Modo: ' + data.modo.toUpperCase();
        el.style.background = cores[data.modo] || '#333';

        document.getElementById('btn-retomar').style.display =
          data.modo === 'parado' ? 'block' : 'none';
      }

      // Telemetria
      if (data.telem) {
        const t = data.telem;
        document.getElementById('t_dist').textContent = t.dist.toFixed(2);
        document.getElementById('t_ang').textContent  = t.angulo.toFixed(1);
        document.getElementById('t_ve').textContent   = t.vel_esq;
        document.getElementById('t_vd').textContent   = t.vel_dir;

        const badge = document.getElementById('tag-badge');
        if (t.tag_vista) {
          badge.textContent      = '🎯 TAG DETECTADA';
          badge.style.background = 'rgba(0,180,0,0.8)';
          badge.style.color      = '#fff';
        } else {
          badge.textContent      = '🔍 Buscando...';
          badge.style.background = 'rgba(200,100,0,0.7)';
          badge.style.color      = '#fff';
        }
      }
    };
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

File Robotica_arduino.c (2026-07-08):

#include <AccelStepper.h>

#if !defined(__AVR_ATmega2560__)
#error "Selecione Arduino Mega 2560 em Ferramentas > Placa."
#endif

// ── Pinos Motor LEGO ────────────────────────────────────────────
const int IN1 = 11;
const int IN2 = 10;
const int ENB = 13;

const int IN3 = 9;
const int IN4 = 8;
const int ENA = 12;

// ── Pinos Motor de Passo ─────────────────────────────────────────
const int pino_step = 4;
const int pino_dir = 5;
const int pino_enable = 3;
const int pino_vcc = 6;

// ── Parâmetros ───────────────────────────────────────────────────
const int PASSOS_POR_TECLA = 180;
const int ALTURA_MAX_PASSOS = 3000;
const unsigned long WATCHDOG_MS = 3000;

// ── Estado ───────────────────────────────────────────────────────
AccelStepper garfo(1, pino_step, pino_dir);
String buffer = "";
int passos_acumulados = 0;
unsigned long ultimo_recebimento = 0;

// ── Motores LEGO ─────────────────────────────────────────────────
// Raspberry manda: "DE:1,VE:150,DD:1,VD:150"
// DE/DD: direção esq/dir  (1=frente, -1=ré, 0=parado)
// VE/VD: velocidade esq/dir (0-180, já calculado pelo Pi)
void moverRodas(int dir_esq, int vel_esq, int dir_dir, int vel_dir) {
  // Motor A — esquerda
  if (dir_esq > 0) {
    digitalWrite(IN1, HIGH);
    digitalWrite(IN2, LOW);
  } else if (dir_esq < 0) {
    digitalWrite(IN1, LOW);
    digitalWrite(IN2, HIGH);
  } else {
    digitalWrite(IN1, LOW);
    digitalWrite(IN2, LOW);
  }

  // Motor B — direita
  if (dir_dir > 0) {
    digitalWrite(IN3, HIGH);
    digitalWrite(IN4, LOW);
  } else if (dir_dir < 0) {
    digitalWrite(IN3, LOW);
    digitalWrite(IN4, HIGH);
  } else {
    digitalWrite(IN3, LOW);
    digitalWrite(IN4, LOW);
  }

  // Aplica PWM nos dois ao mesmo tempo (minimiza delay entre rodas)
  analogWrite(ENA, vel_esq);
  analogWrite(ENB, vel_dir);
}

void parar() {
  digitalWrite(IN1, LOW);
  digitalWrite(IN2, LOW);
  digitalWrite(IN3, LOW);
  digitalWrite(IN4, LOW);
  analogWrite(ENA, 0);
  analogWrite(ENB, 0);
}

// ── Motor de Passo ───────────────────────────────────────────────
void garfoSubir(int passos) {
  if (passos_acumulados + passos > ALTURA_MAX_PASSOS) {
    Serial.println("LIMITE: garfo no topo.");
    return;
  }
  digitalWrite(pino_enable, HIGH);
  garfo.move(passos);
  while (garfo.distanceToGo() != 0) garfo.run();
  digitalWrite(pino_enable, LOW);
  passos_acumulados += passos;
  Serial.println("Garfo subiu. Pos: " + String(passos_acumulados));
}

void garfoDescer(int passos) {
  if (passos_acumulados - passos < 0) {
    Serial.println("LIMITE: garfo no fundo.");
    return;
  }
  digitalWrite(pino_enable, HIGH);
  garfo.move(-passos);
  while (garfo.distanceToGo() != 0) garfo.run();
  digitalWrite(pino_enable, LOW);
  passos_acumulados -= passos;
  Serial.println("Garfo desceu. Pos: " + String(passos_acumulados));
}

// ── Parser ───────────────────────────────────────────────────────
// Formatos recebidos:
//   "DE:1,VE:150,DD:1,VD:150\n"   → move rodas
//   "PARAR\n"                      → para tudo
//   "SUBIR\n"                      → garfo sobe
//   "DESCER\n"                     → garfo desce
void executarComando(String cmd) {
  ultimo_recebimento = millis();

  if (cmd == "PARAR") {
    parar();

  } else if (cmd == "SUBIR") {
    garfoSubir(PASSOS_POR_TECLA);

  } else if (cmd == "DESCER") {
    garfoDescer(PASSOS_POR_TECLA);

  } else if (cmd.startsWith("DE:")) {
    // Extrai os 4 valores
    // Formato: DE:1,VE:150,DD:1,VD:150
    int i0 = cmd.indexOf("DE:") + 3;
    int i1 = cmd.indexOf(",VE:");
    int j1 = i1 + 4;
    int i2 = cmd.indexOf(",DD:");
    int j2 = i2 + 4;
    int i3 = cmd.indexOf(",VD:");
    int j3 = i3 + 4;

    int dir_esq = cmd.substring(i0, i1).toInt();
    int vel_esq = cmd.substring(j1, i2).toInt();
    int dir_dir = cmd.substring(j2, i3).toInt();
    int vel_dir = cmd.substring(j3).toInt();

    moverRodas(dir_esq, vel_esq, dir_dir, vel_dir);

  } else {
    Serial.println("Cmd desconhecido: " + cmd);
  }
}

// ── Setup ────────────────────────────────────────────────────────
void setup() {
  pinMode(IN1, OUTPUT);
  pinMode(IN2, OUTPUT);
  pinMode(ENA, OUTPUT);
  pinMode(IN3, OUTPUT);
  pinMode(IN4, OUTPUT);
  pinMode(ENB, OUTPUT);
  pinMode(pino_vcc, OUTPUT);
  pinMode(pino_enable, OUTPUT);

  digitalWrite(pino_vcc, HIGH);
  digitalWrite(pino_enable, LOW);

  parar();

  garfo.setMaxSpeed(800.0);
  garfo.setAcceleration(400.0);

  Serial.begin(115200);
  ultimo_recebimento = millis();
  Serial.println("Pronto.");
}

// ── Loop ─────────────────────────────────────────────────────────
void loop() {
  if (millis() - ultimo_recebimento > WATCHDOG_MS) {
    parar();
  }

  while (Serial.available()) {
    char c = Serial.read();
    if (c == '\n') {
      buffer.trim();
      if (buffer.length() > 0) executarComando(buffer);
      buffer = "";
    } else {
      buffer += c;
    }
  }
}
